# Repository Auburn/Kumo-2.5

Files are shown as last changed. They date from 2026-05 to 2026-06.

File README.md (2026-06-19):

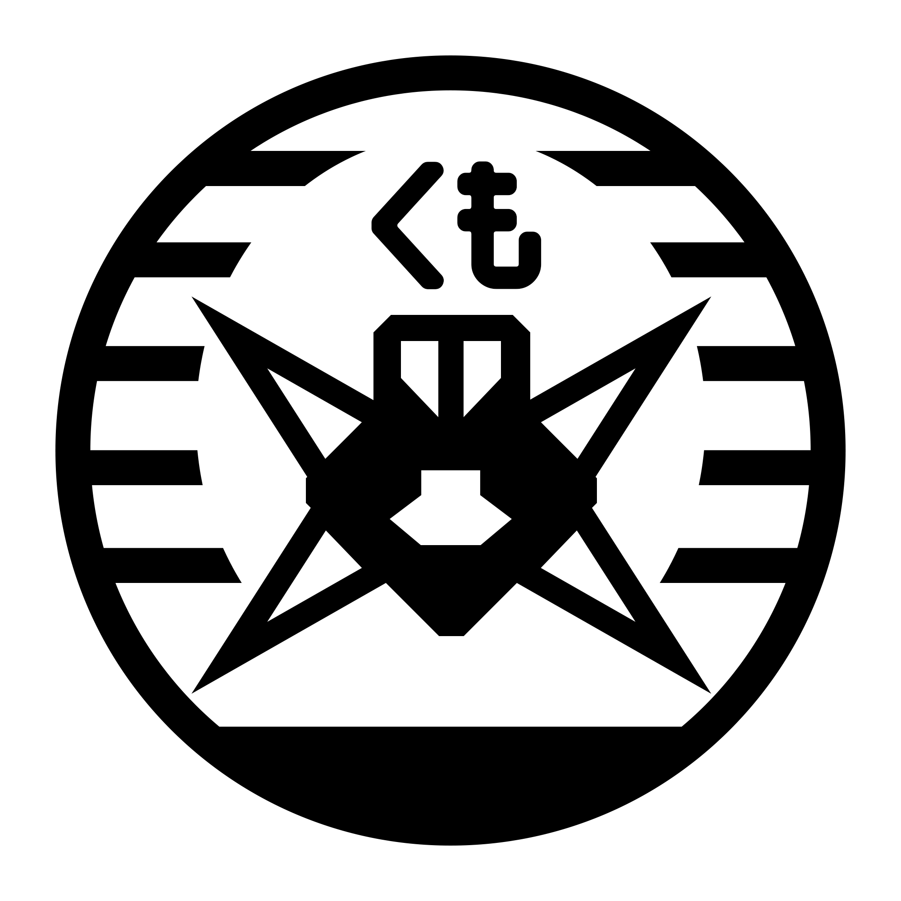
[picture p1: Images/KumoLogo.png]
Kumo Logo


# Kumo 2.5
A 2.5" drone frame. Star shaped dual arm design available both in printable and carbon fiber cut files in [[STL]] and [[CAD]] formats.

This project was born out of the desire for building a robust freestyle 2.5" 2S quad built from the ground up around the HDZero AIO15 and Lux camera. Something with a bit more power and wind resilience than a whoop, but still relatively quiet and survivable to crashes. Some of the mono-body frames seem to have lightweight arms that are a bit flimsy, thus the star shape was opted in the newer versions of the Kumo frame. 

My vision for this project was to create an open-source frame design that could be iterated and shared with accessible options. 

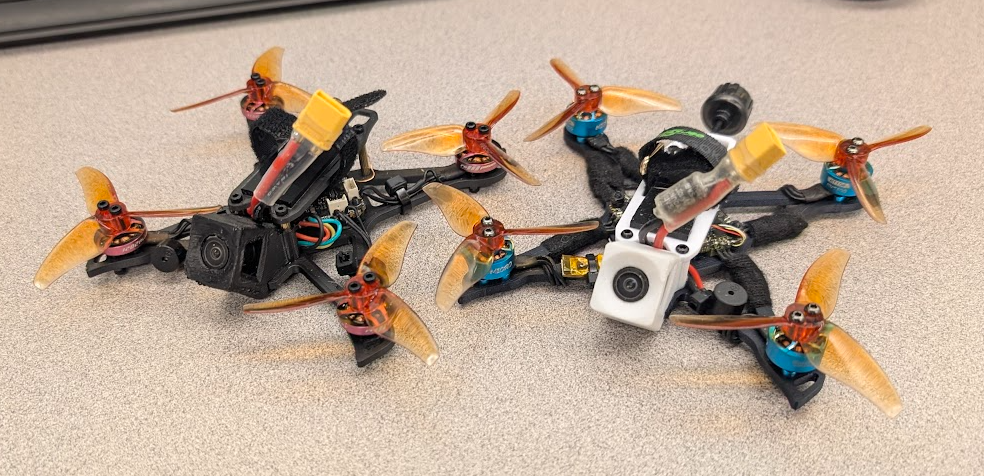
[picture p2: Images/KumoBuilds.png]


## Contents

1. [Elements](#elements)
2. [Design](#design)
3. [Recommended Setup](#recommended-setup)
4. [Tune](#Tune)
5. [Videos](#Videos)
6. [Authors](#Authors)
7. [Versions](#Versions)
8. [Changelog](#Changelog)

## Elements

- Open Source as CC-BY 4.0
- Designed as a more robust toothpick with AIO or other light stacks. Primarily the HDZero AIO15
- Squished X geometry (4mm stubbier to get the props a bit less in frame)
- Slam deck to keep center of gravity along propeller line
- Rigid Design
- Camera mount designed for 25/35deg HDZero Lux. Also compatible with the [Kayoumini camera mounts ](https://www.printables.com/model/1330393-kayoumini-camera-tpu-print-support)
## Design

### Frame Design
Cutout for HDZero AIO15 to reduce height while also keeping ports accessible.
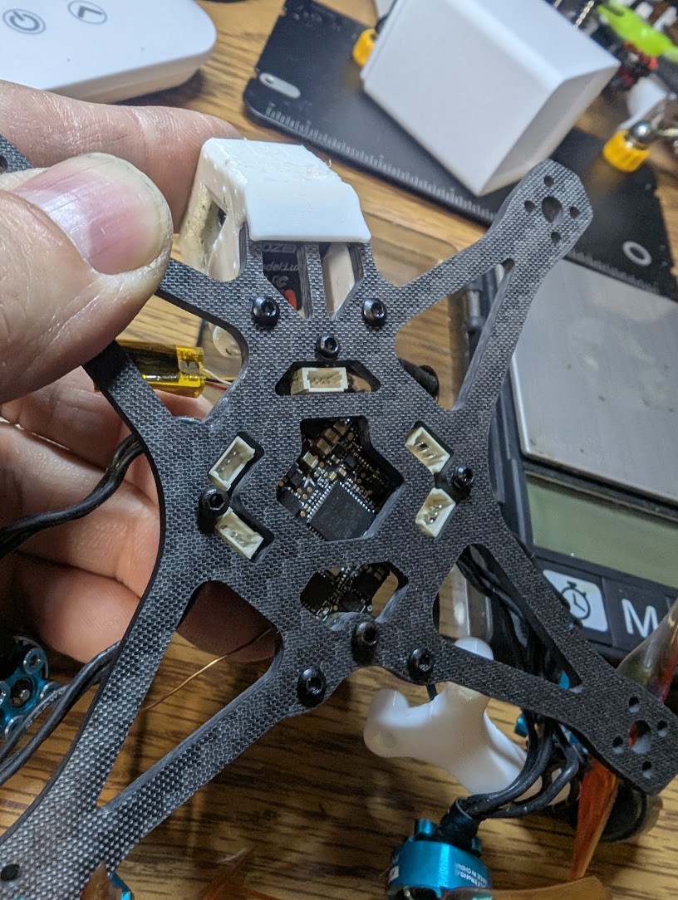
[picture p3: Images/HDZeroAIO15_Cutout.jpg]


Squished X geometry set at just under 85deg between front/back. Reduces prop in frame, however roll vs pitch movement requires less inertia due to weight distribution along Y axis.
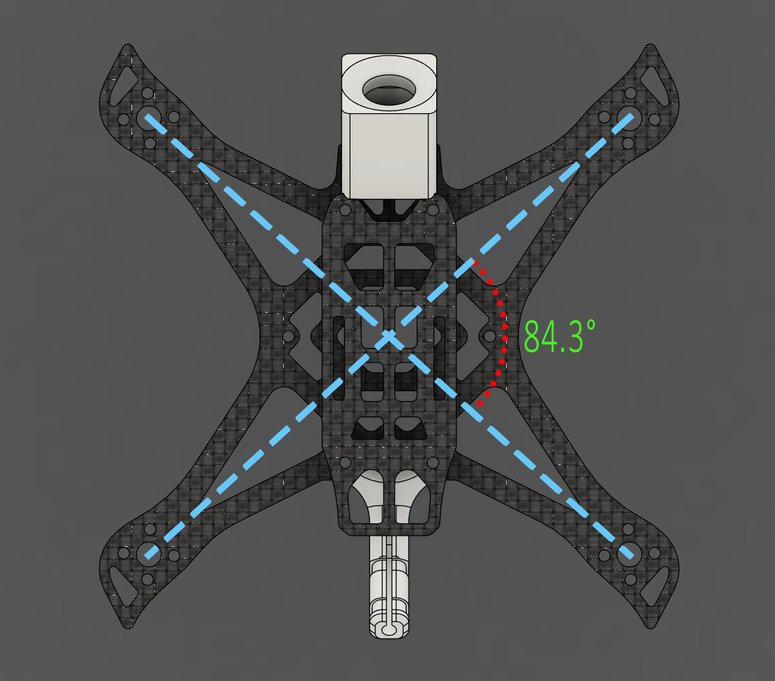
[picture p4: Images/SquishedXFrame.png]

#### Slam Deck and Center of gravity
Keeping the center of gravity low with 8-12mm standoffs helps reduce effort in flips. Sweet spot for avoiding battery strikes with props sits around 10-11mm standoff while also providing plenty of room for wire routing. For a tighter fit, 8-9mm standoffs can be used. Photo below is of 11mm standoff.
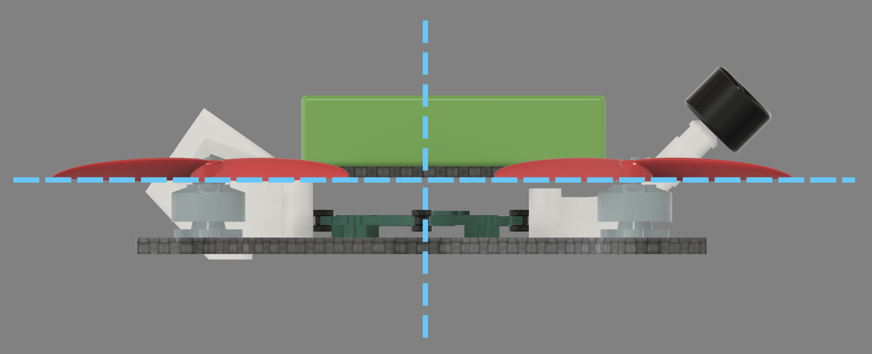
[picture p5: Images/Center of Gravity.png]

### Camera mount
Designed with compatibility in mind with camera mounts from [Kayoumini](https://www.printables.com/model/1330393-kayoumini-camera-tpu-print-support) This sample mount for HDZero Lux at 35 degrees offers a balance between racing and freestyle. Print in TPU to dampen vibrations and soften impacts.
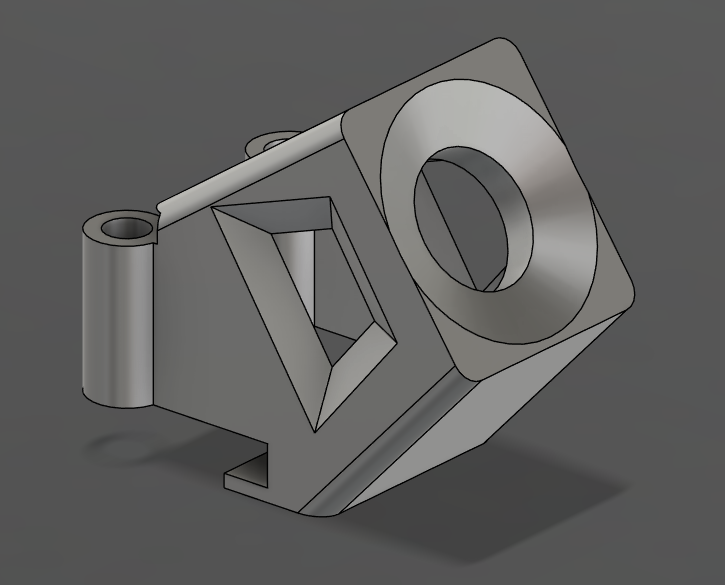
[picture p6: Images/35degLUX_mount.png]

### Printed frame vs Carbon Fiber
Original test builds used a variety of 3D printed versions yielding varying stiffness and weight. 
Thickened printed version in PETG-CF to increase stiffness and improve impact resilience. In this version I was still using the stick antenna from BetaFPV
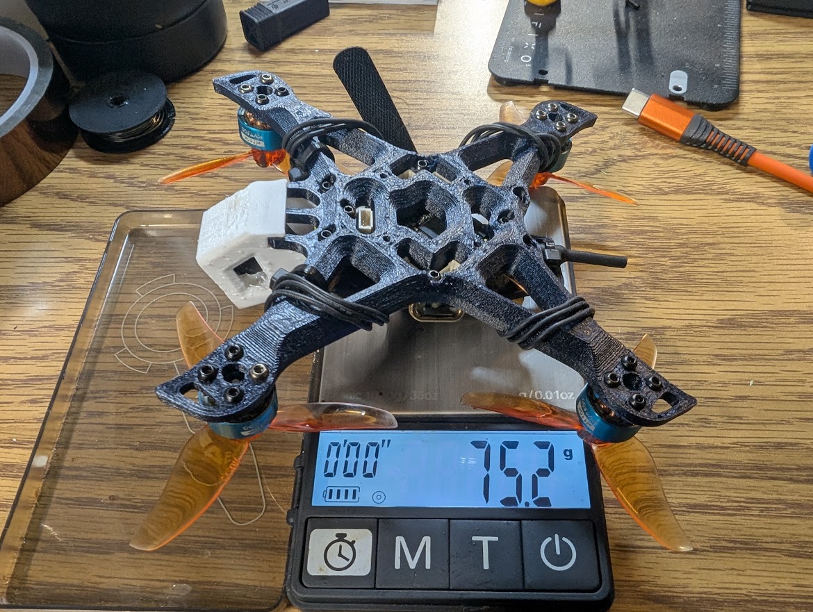
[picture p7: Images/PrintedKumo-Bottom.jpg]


Stubby version of frame cut from 2.5mm Carbon Fiber with RHCP antenna for improved weight and video signal
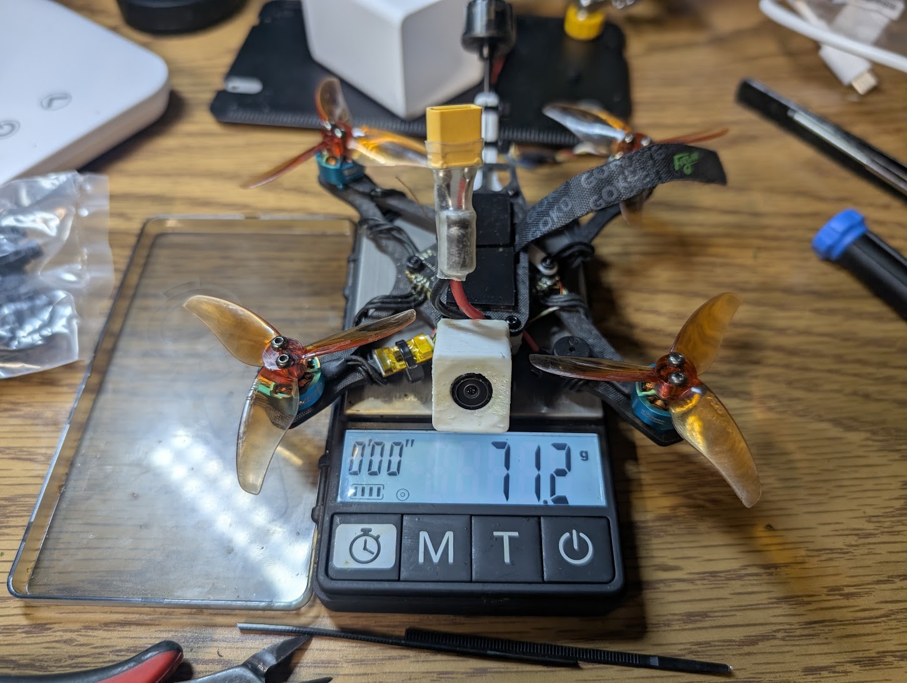
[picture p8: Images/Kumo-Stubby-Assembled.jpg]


Noise comparison between tunes of 3D printed (blue) and Carbon Fiber (red) variants of frame. The CF frame seemed to produce close to 10dB less noise thus requiring much less filtering  to improve responsiveness.
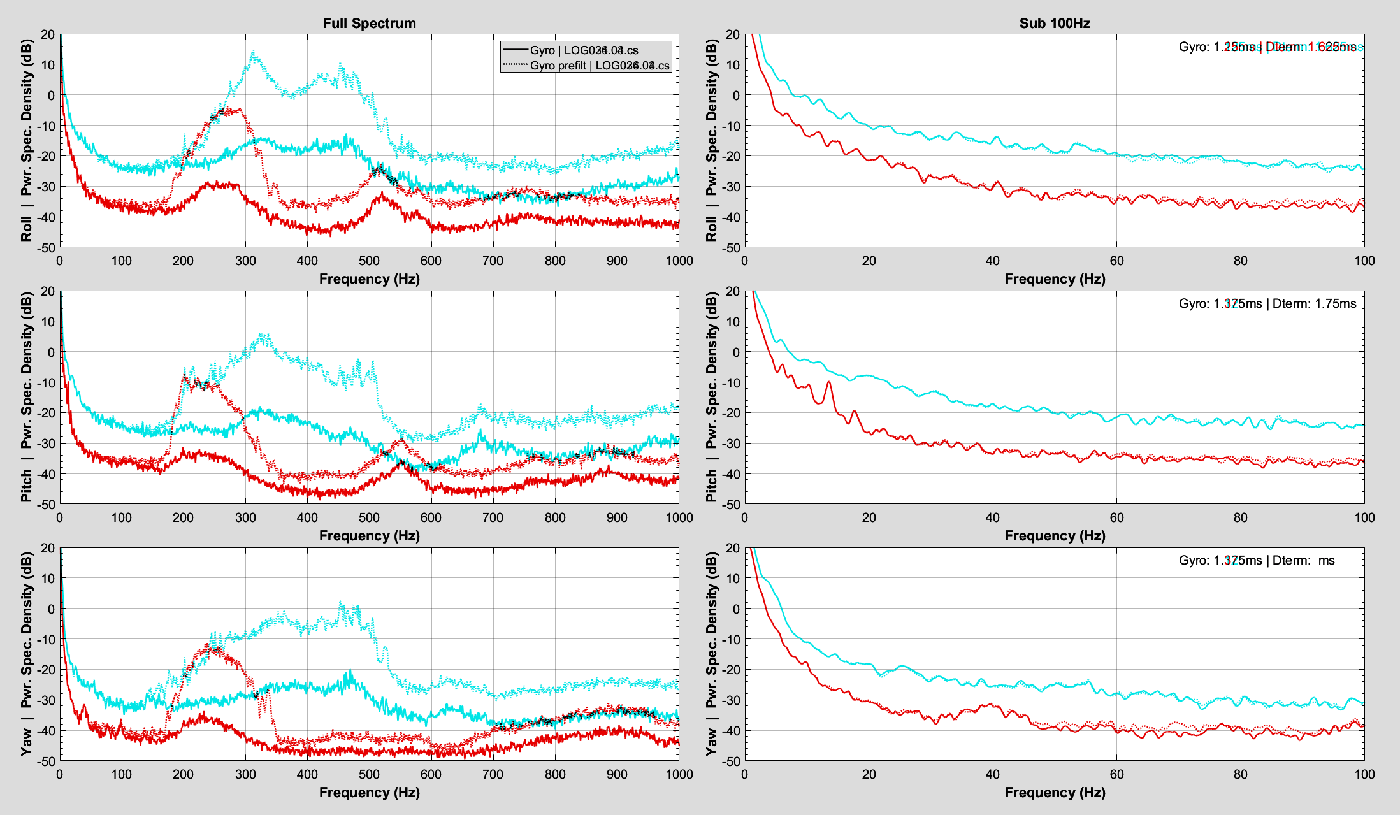
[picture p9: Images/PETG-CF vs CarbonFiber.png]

### Stubby vs Sharp
I created a light weight version of the frame for increased agility (and likely more fragile) stubby version weighing in at 10g for the base. Cut from 2.5mm thick CF 6K 2x2 Twill weave
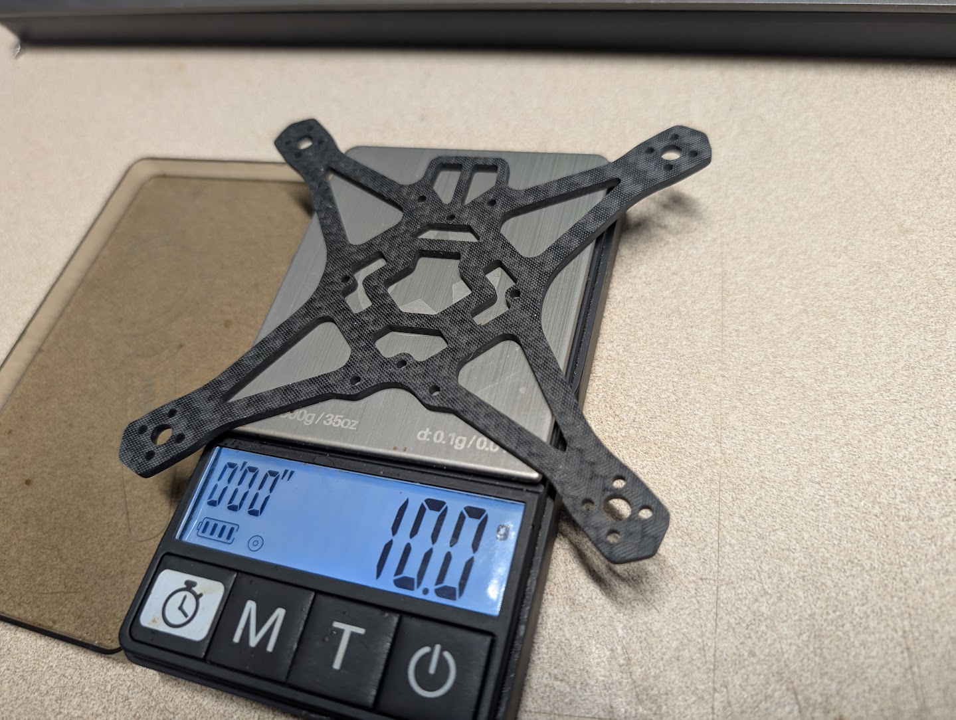
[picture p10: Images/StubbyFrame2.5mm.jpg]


And a heavier 3.4mm carbon (was listed as 3.1) cut from 6K 2x2 Twill weave. Added protrusion to add material in front of motor. Designed for more aggressive bashing, but adds 4.4g to previous design.
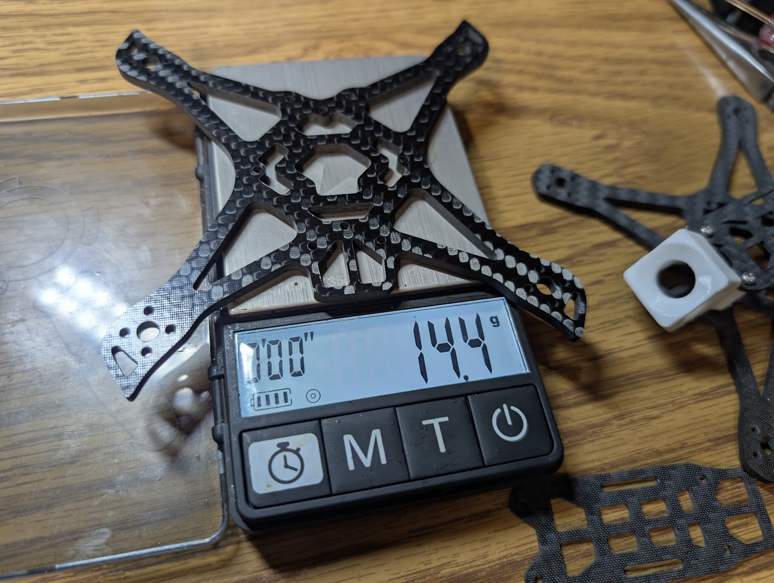
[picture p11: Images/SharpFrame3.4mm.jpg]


TPU plus CF stubby, top plate, standoffs and main screws comes in at 17.5g
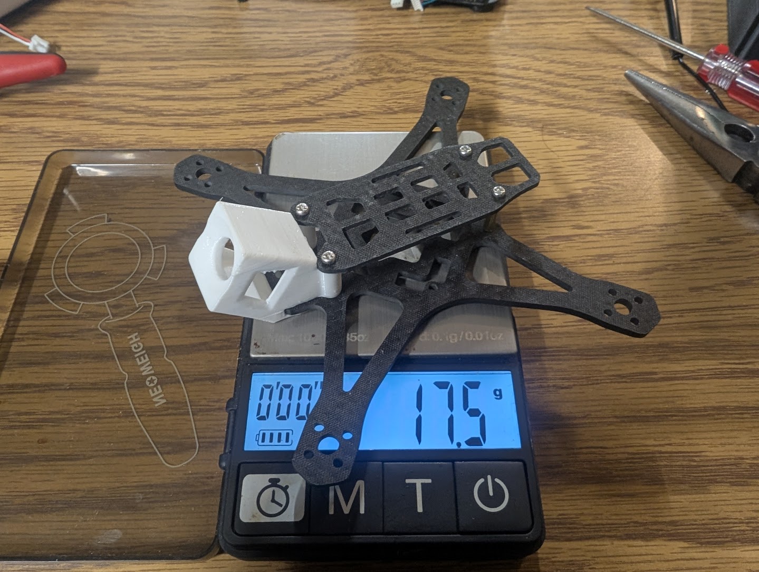
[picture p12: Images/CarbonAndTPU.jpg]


Top plate cut from 1.5mm CF 6k 2x2 twill. Designed with cut out towards the front for battery lead and extension on the back for battery deck/attachment for antenna.
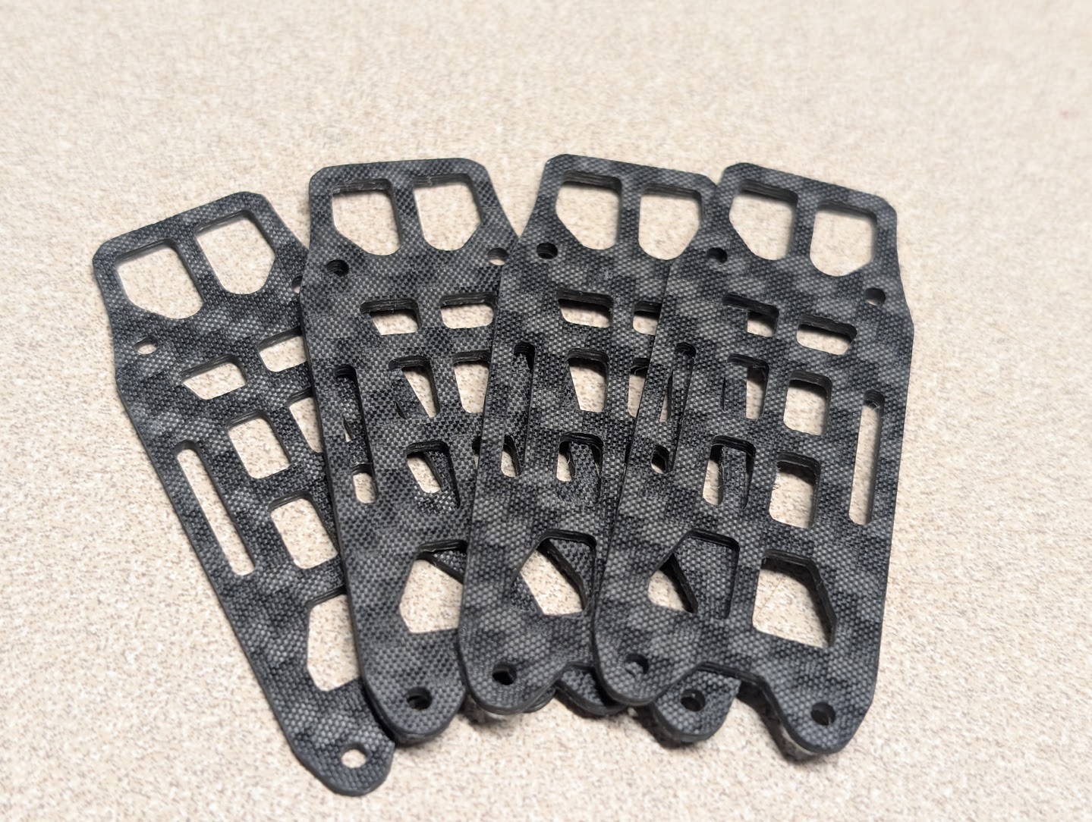
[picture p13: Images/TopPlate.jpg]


## Recommended-Setup

> [!NOTE]
> *At this size, every gram counts, so tradeoffs must be made to manage durability, range, battery/flight time and flight dynamics.* 

Key considerations for building: 
1. **Weight** of components: Antenna type, TPU mounts and motor guards, battery size. My goa was to have a dry weight under 70g and an AUW of under 100g. For this I found the stubby frame at 2.5mm thick with a circular polarized antenna provided a decent compromise in weight, range, signal quality. For a more racing style setup, I tested the Twiglet frame that allowed me to get as low as 50g using 12025 11000kv motors
2. **Power**: For motor and battery size considerations, I found the HDZero 15A felt solid with 2S in terms of maneuverability. 3S seemed to add quite a bit of weight which required much more throttle to power through sharp corners. With the 2S battery, finding a balance between 8000-11000kv would likely be ideal. I opted for heavier 1104 7500kv which added 4g, but gave me a bit more control with 2" pitch props over 12025 11000kv. That being said, the 12025 felt faster and twitchier, which may be preferable for pilots with better reaction time.
3. **Props**: I tested with GF 2520, 2540 and AVAN Rush (1.9" pitch). By performance, it felt like the Gemfan 2520 yielded the best performance and was less noisy than the AVAN rush. As nice as the AVAN rush felt, it had a high pitched scream that was somewhat unpleasant (and may be a nuisance around others). The GF2540 was explosive in power and worked well with the 1104 motors, but seemed better suited for racing and higher speed lines.
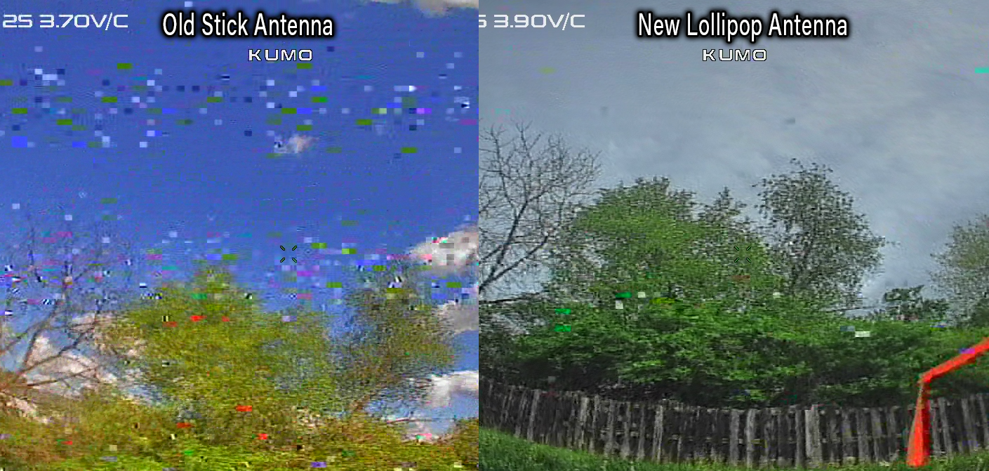
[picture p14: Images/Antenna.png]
4. **Antenna**: The default stick antenna that comes with the HDZero AIO15 caused a bunch of problems and no matter where I placed the antenna, I always seemed to struggle with noise and range issues. Opting for a circular polarized antenna that I could push further away from the body seemed to help quite a bit in transmission quality during punch-outs. I had tried other stick antennas such as a BetaFPV linear antenna for Air75, but performance still seemed quite bad. 
5. **Accessories**: The HDZero AIO15 does not come with a blackbox, which means if you wish to tune, you will need to attach an external recorder. I used a Flywoo OpenLager, which helped narrow down on some of the noise and responsiveness to cut down on propwash. I also added a simple buzzer as this tiny thing is super easy to lose. Adding 1g worth of wire/buzzer/ziptie is totally worth it in my book.
### Example build:
- HDZero AIO15 + Lux camera
- T-motor 1104 7500kv
- Gemfan Hurricane 2520
- Newbeedrone RHCP Honey Dipper Antenna
- 2S battery (450-580mAh)
- Active Buzzer and Flywoo OpenLager blackbox
## Tune
Betaflight defaults were fairly decent for me, but minor tweaks have helped improve propwash. Carbon fiber frame also was less susceptible to vibrations and required less filters.

PID profile settings are almost stock. I used PIDToolbox and suggestions from [this video](https://www.youtube.com/watch?v=ehvQm8Rqrzk). Angle limit was set to 30 during auto-wobble script.
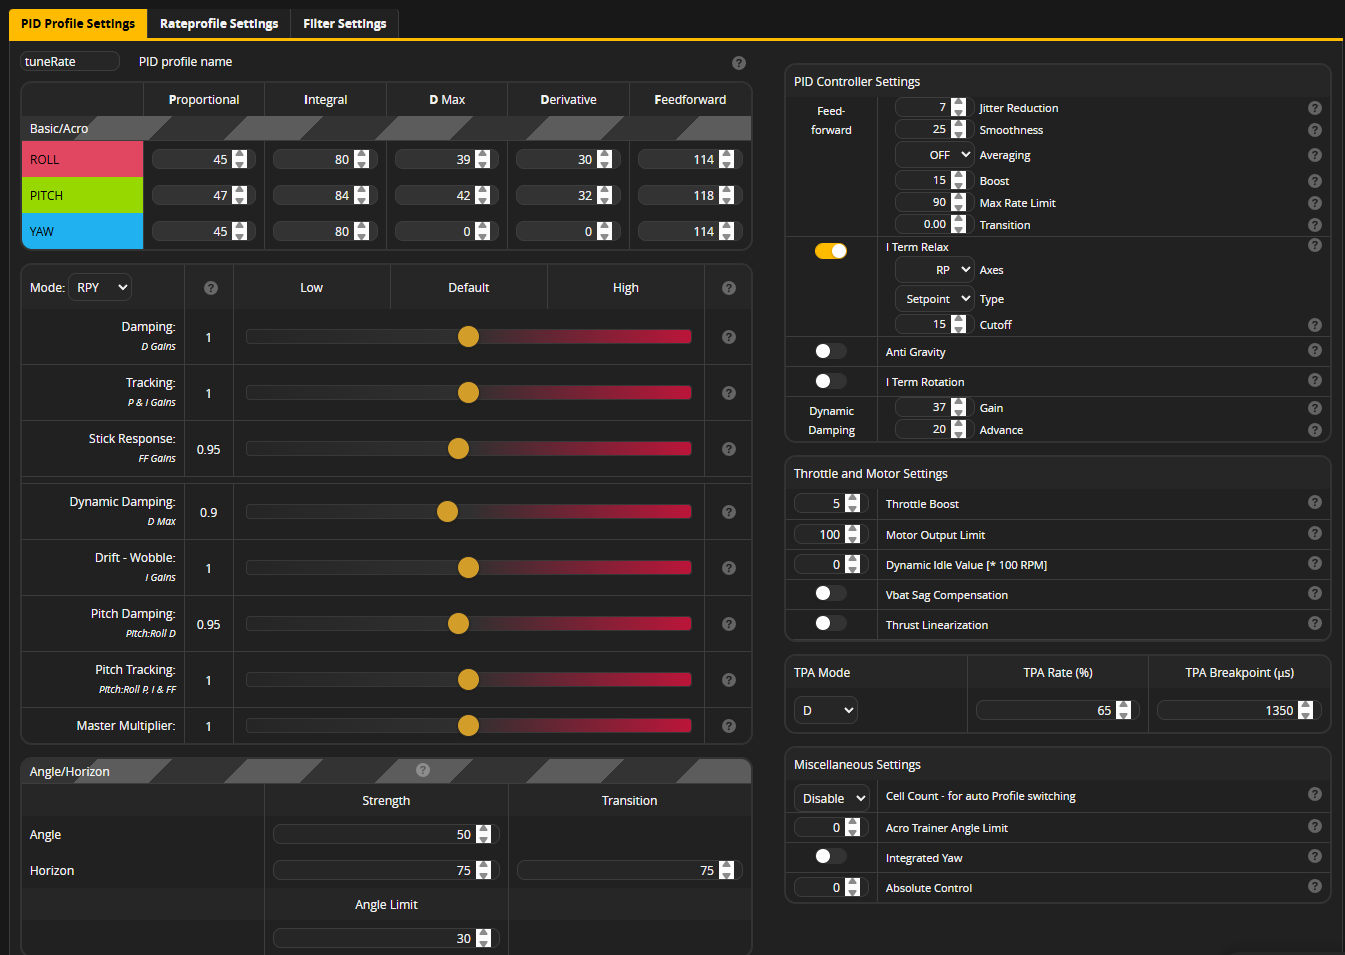
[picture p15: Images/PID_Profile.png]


For the filter, removing the first lowpass and tightening the notch filters helped reduce delay while still cleaning the noise.
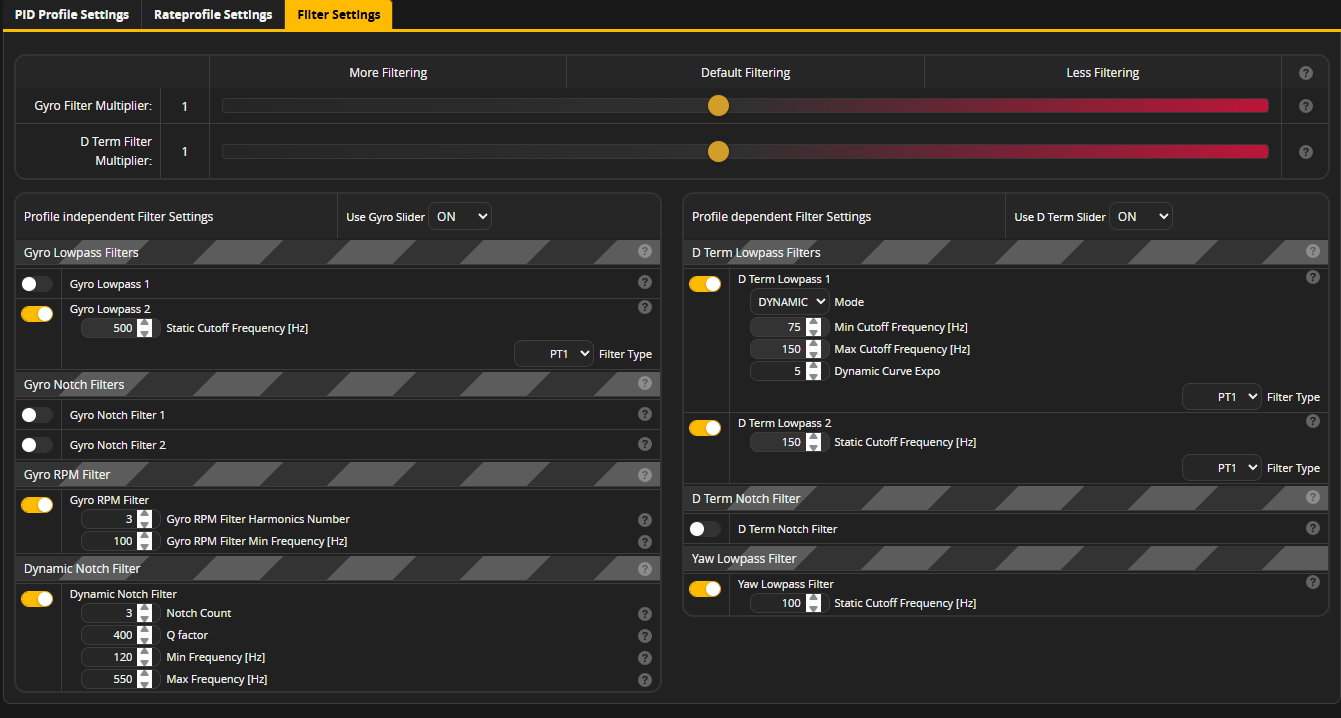
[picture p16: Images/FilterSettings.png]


I also set the filter weights and q value to the following:
`rpm_filter_weights = 100,60,70`
`rpm_filter_q = 1000`

Resulting first harmonics were still present, with **Roll** requiring a bit more attention, yet fairly solid from what I can tell.
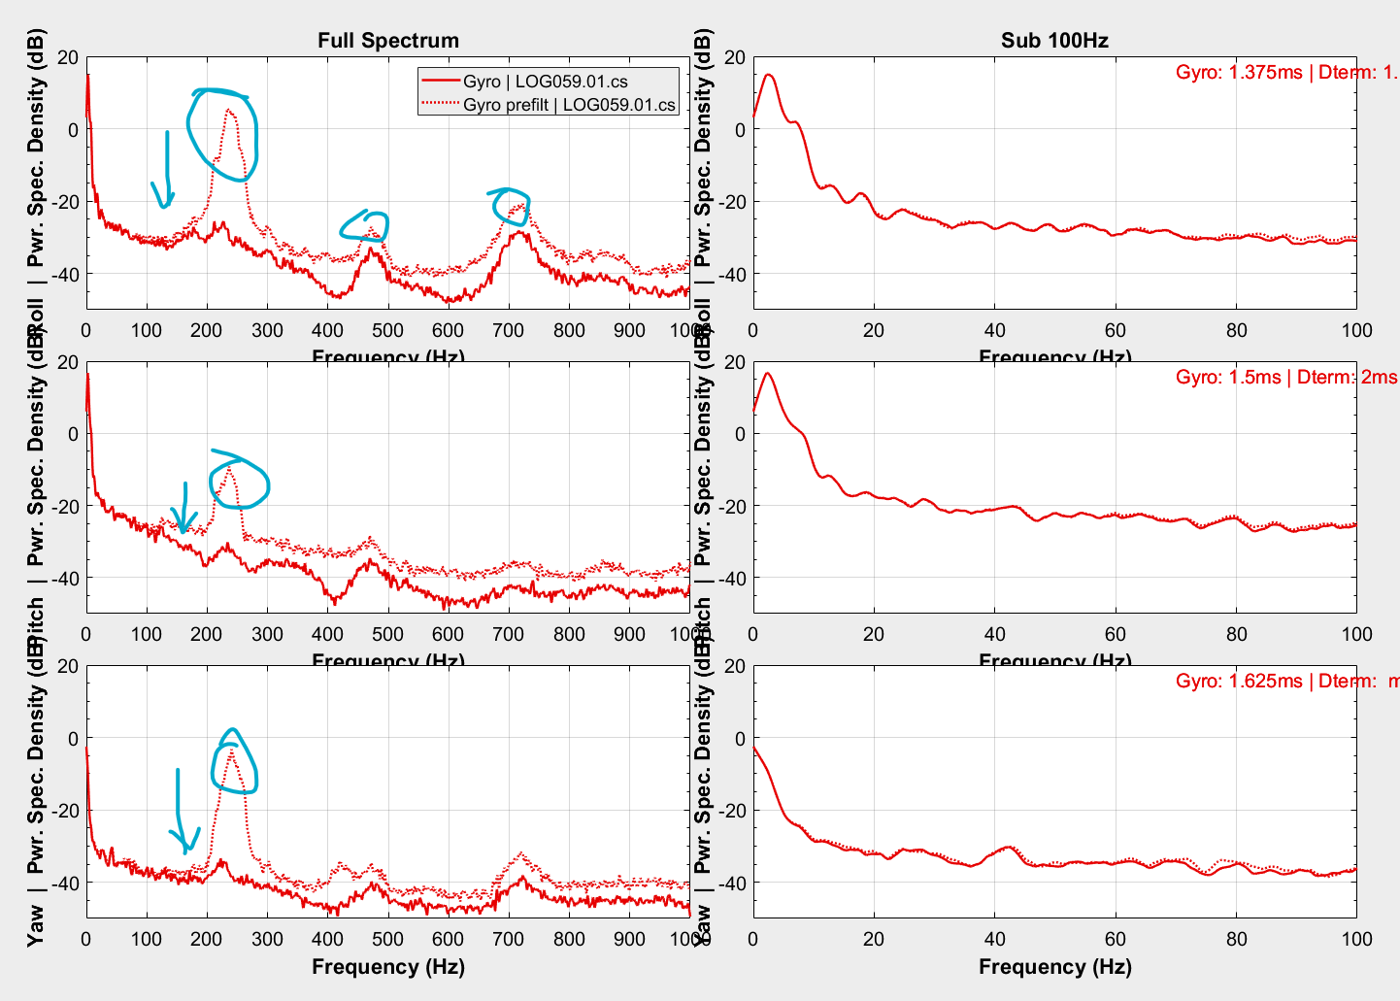
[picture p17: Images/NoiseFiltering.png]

## Videos

Kumo Frame analysis for stress concentration: (front impact)


Kumo Frame printed first flight

First Flight of 3D print|697 (http://www.youtube.com/watch?v=SoQ7cqYJ5XA)

Kumo Frame CNC cut on Millennium Mill

CNC Cut Stubby|697 (http://www.youtube.com/watch?v=ESLiF3WcUNc)
## Authors
The Kumo project was designed and contributed by:
- [Kumoi](https://github.com/kumoishibo): primary designer
- [Auburn](https://github.com/Auburn): Slim 3D print version & design contributions to main
## Versions
For a list of past created iterations, here is a [Google sheet of various versions with specs, components and photos](https://docs.google.com/spreadsheets/d/1-7FYr2rQ0BzAxG1OKXEforiyXhu9mfht/edit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)
List of file versions in repo:
- Kumo Main Version (Sharp version) 
- Kumo Slim (less material, more fragile)
- Kumo Stubby (similar to sharp version with stubby motor mount)
- Outdated versions (single arm design):
	- Kumo Frog (quite heavy and poorly designed skeletonized parts)
	- Kumo ChunkyFrog (more material, more cutouts, poor access to usb port)
	- Kumo Offaxis (interesting attempt to merge top/bottom plate with flipped parts. Too heavy, poor skeletonization, no top/bottom usb access, no battery strap)
## Changelog
- 6-19-2026: Additions of new slim 3D printable versions by [Auburn](https://github.com/Auburn) 
- 5-21-2026: Added Git Discussion, fixed M2 clearance on bottom AIO hole (Thank you Auburn!)
- 5-19-2026: Completed Documentation V1 and published to Reddit
- 5-5-2026: CNC cut stubby frame (youtube video above)
- 4-24-2026: [Tested with 3S... a bit scary](https://www.reddit.com/r/fpv/comments/1suqytk/probably_wasnt_meant_for_3s/)
- 4-20-2026: First flight of Star shaped Kumo frame (youtube video above)
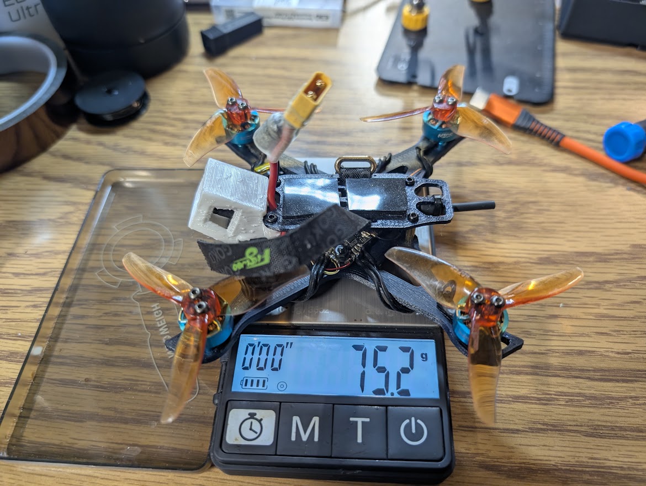
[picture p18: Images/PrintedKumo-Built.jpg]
- 4-19-2026: 3D printed version of frame built
- 4-16-2026: Experimental version of 3D printed frame. Felt very flimsy, added some material around standoff mounts.
- 4-6-2026: Camera mount complete
- 3-28-2026: Experimenting with [Flipped Z design](/CAD/OutdatedDesigns/Frog_MainBody.step)
- 3-27-2026: Stress tests for impact yields concerns with single arm design
- 3-25-2026: First version of Kumo frame  designed (looks like a squished frog)

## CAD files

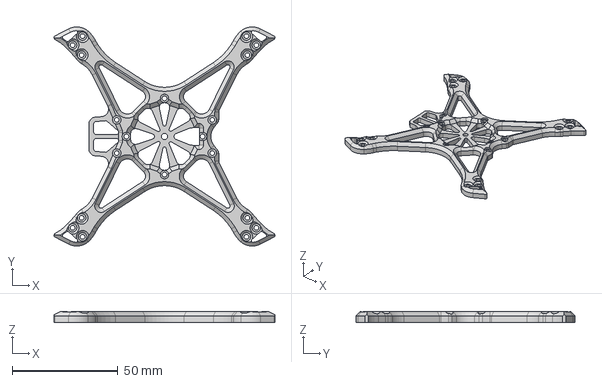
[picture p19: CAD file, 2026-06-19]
CAD/AlternateVersions/Kumo-MainBody-3DPrintSlim.step
104.6 x 103.8 x 5.00 mm

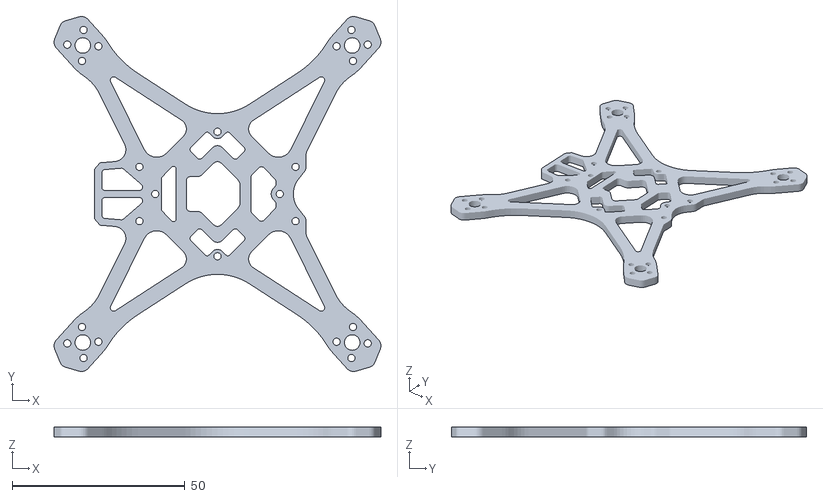
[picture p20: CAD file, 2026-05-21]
STL/AlternateVersions/Kumo-MainBody-Stubby-2.stl
94.6 x 102.8 x 3.00

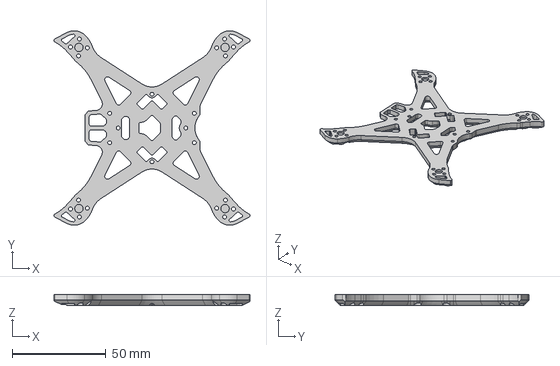
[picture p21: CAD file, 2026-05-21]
CAD/AlternateVersions/Kumo-MainBody_3DPrintableBasher.step
104.6 x 103.8 x 6.00 mm

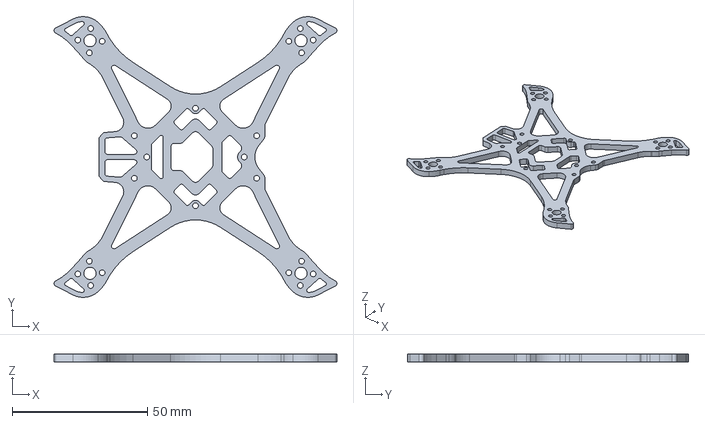
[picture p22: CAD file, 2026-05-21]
CAD/Kumo-MainBody.step
104.6 x 103.8 x 3.00 mm

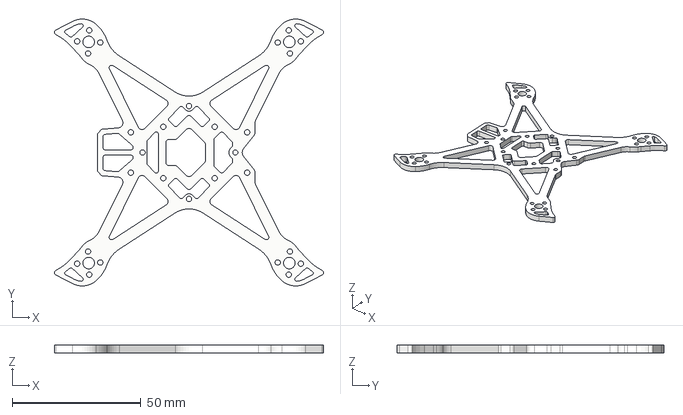
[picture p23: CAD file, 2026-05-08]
CAD/AlternateVersions/Kumo-MainBody-Slim.step
104.6 x 103.8 x 3.00 mm

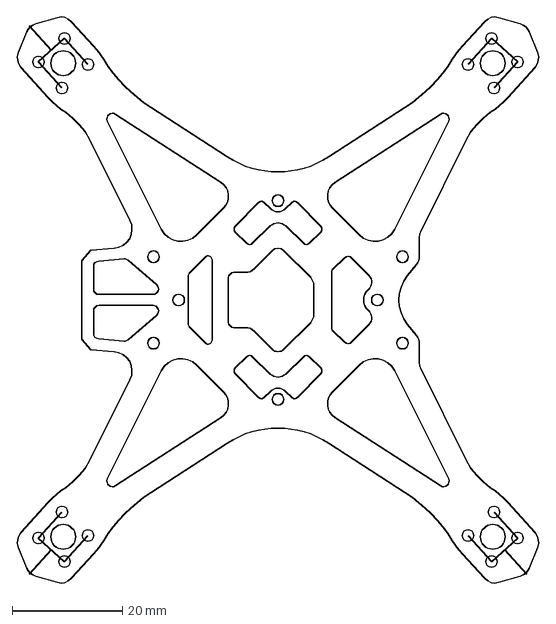
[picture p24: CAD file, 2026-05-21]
CAD/Stubby_Version.dxf
95.0 x 103.1 mm

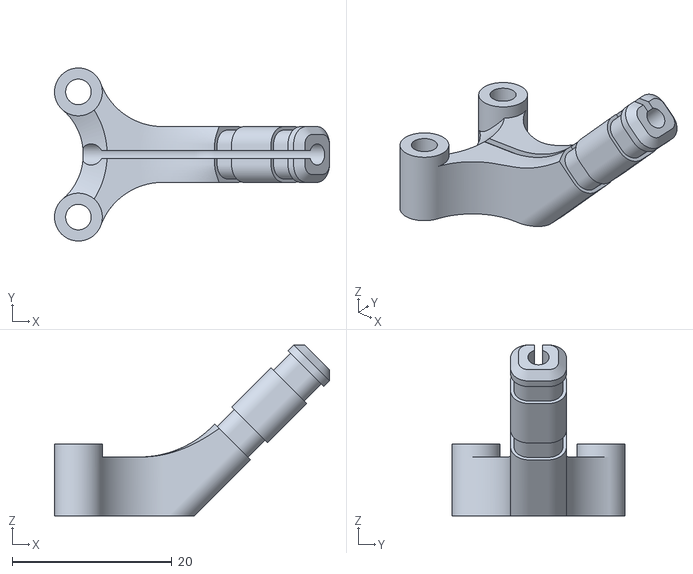
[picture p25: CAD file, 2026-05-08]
STL/AntennaMount-CP_D2.stl
34.5 x 21.7 x 21.4

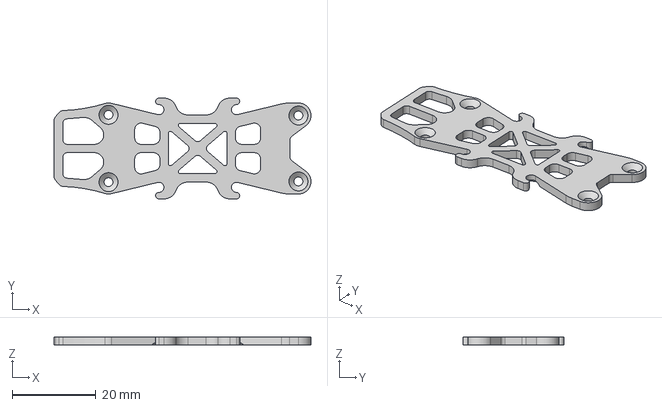
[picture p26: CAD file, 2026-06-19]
CAD/AlternateVersions/Kumo-TopPlate-Hooks.step
61.2 x 24.0 x 2.00 mm

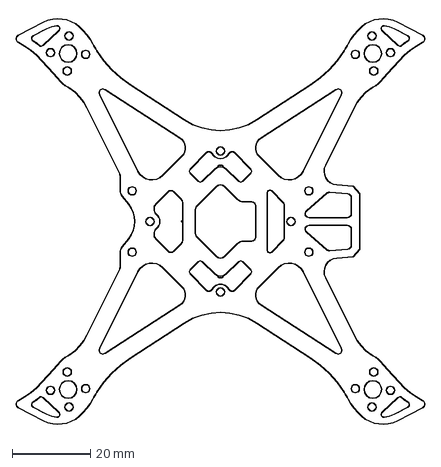
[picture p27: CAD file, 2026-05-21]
CAD/Standard_Version.dxf
104.6 x 105.0 mm

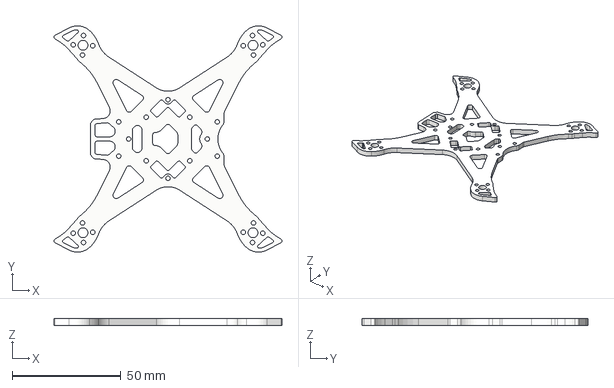
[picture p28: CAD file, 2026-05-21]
CAD/AlternateVersions/Kumo-ThickBase-Flat.step
104.6 x 103.8 x 3.00 mm

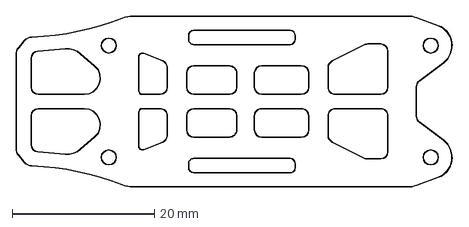
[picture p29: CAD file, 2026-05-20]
CAD/TopPlate.dxf
61.4 x 24.0 mm

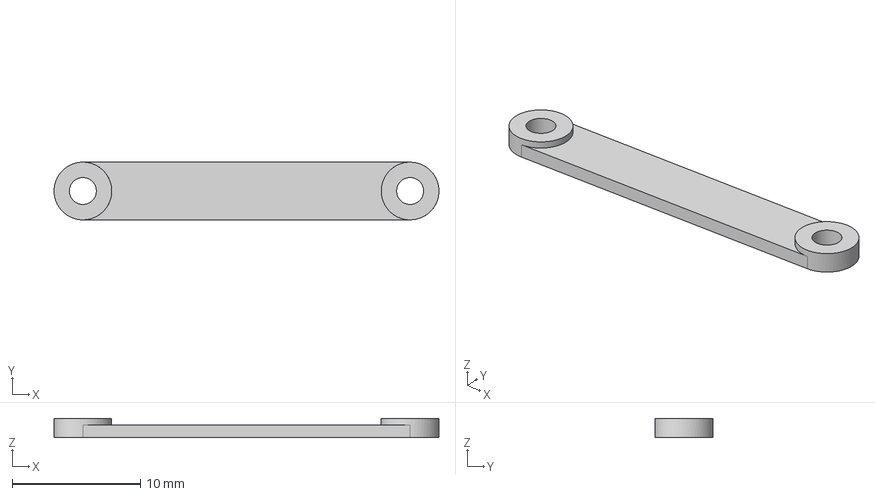
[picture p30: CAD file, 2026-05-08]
CAD/U.FL_Clamp.step
30.0 x 4.50 x 1.50 mm

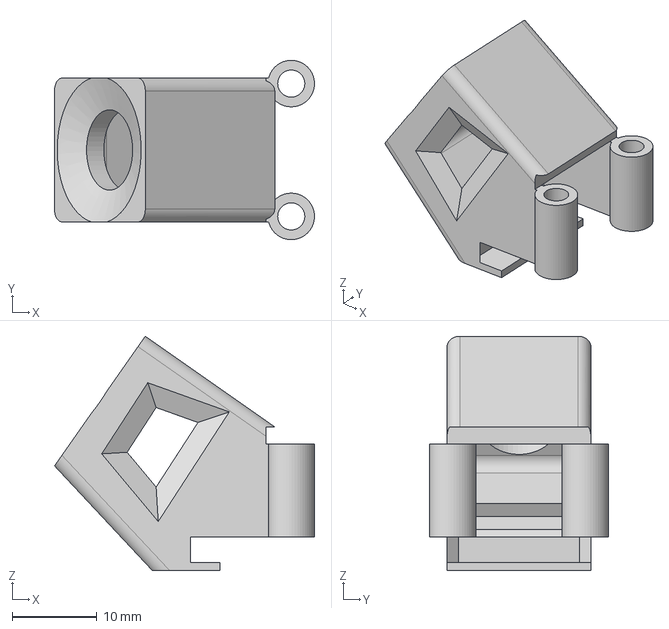
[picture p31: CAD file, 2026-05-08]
CAD/35degLUX_11mmStandoff.step
30.7 x 21.2 x 27.7 mm

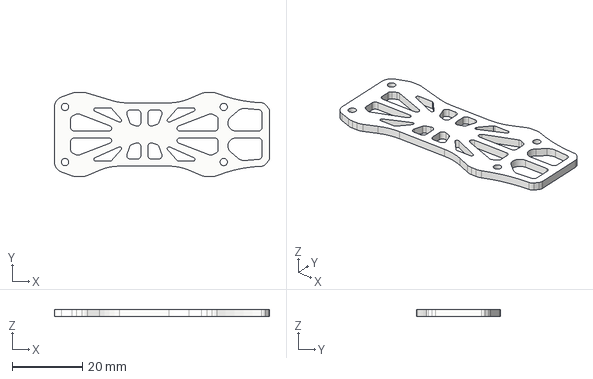
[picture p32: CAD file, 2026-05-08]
CAD/AlternateVersions/Kumo-TopPlate-Slim.step
61.2 x 24.0 x 2.00 mm

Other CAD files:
CAD/AlternateVersions/Kumo-MainBody-Stubby-2.5mm.step
CAD/AntennaMount-CP_D4.25mm.step
CAD/25degLUX_9mmStandoff.step
CAD/AlternateVersions/AntennaMount-CP_TopFront_D2.5mm.step
CAD/25degLUX_11mmStandoff.step
CAD/35degLUX_9mmStandoff.step
CAD/AlternateVersions/Kumo-MainBody-3DPrintSlim.f3d
CAD/AlternateVersions/Kumo-TopPlate-Hooks.f3d
CAD/AntennaMount-CP_D2.65mm.step
CAD/Kumo-TopPlate.step
CAD/OutdatedDesigns/ChunkyFrog_MainBody.step
CAD/OutdatedDesigns/Frog_MainBody.step
CAD/OutdatedDesigns/OffAxis_MainBody.step
STL/25degLUX_11mmStandoff.stl
STL/25degLUX_9mmStandoff.stl
STL/35degLUX_11mmStandoff.stl
STL/35degLUX_9mmStandoff.stl
STL/AlternateVersions/Kumo-MainBody-3DPrintSlim.stl
STL/AlternateVersions/Kumo-MainBody-Slim.stl
STL/AlternateVersions/Kumo-MainBody_3DPrintableBasher.stl
STL/AlternateVersions/Kumo-ThickBase-Flat.stl
STL/AlternateVersions/Kumo-TopPlate-Hooks.stl
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

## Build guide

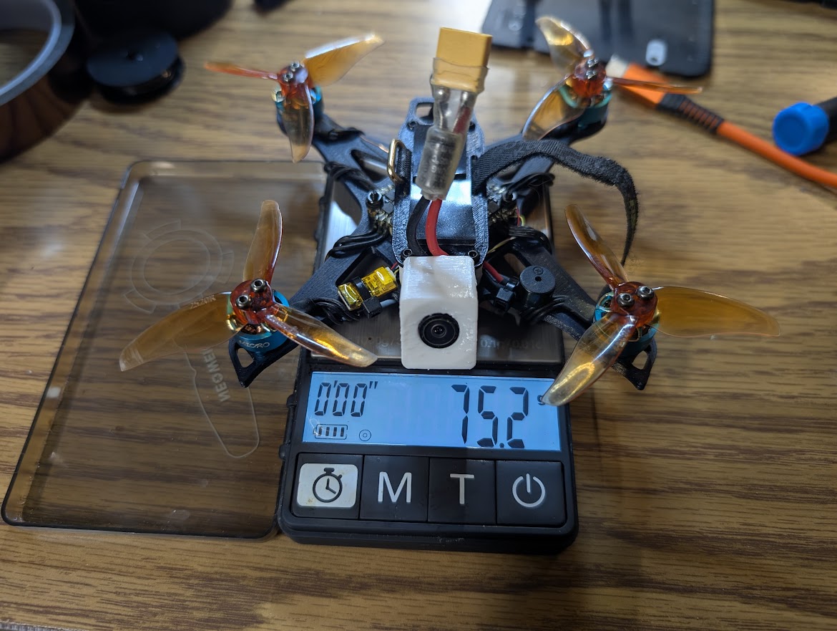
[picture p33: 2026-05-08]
Images/PrintedKumo-BuiltFront.jpg

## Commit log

2026-05-19 Filter results, author and tune info
    Filter results, author and tune info
2026-05-20 Added DXF files for Plates and F3D
    [Standard_Version.dxf, Stubby_Version.dxf, TopPlate.dxf]
2026-05-21 Fixed M2 clearance on botttom AIO hole
    Bottom AIO M2 hole was fixed to be 2.1mm instead of 2mm
    [Kumo-MainBody-Stubby-2.5mm.step, Kumo-MainBody-Stubby-2.stl, Kumo-MainBody.step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]
2026-06-15 3D print slim + top plate hooks CAD files
    [Kumo-MainBody-3DPrintSlim.f3d, Kumo-MainBody-3DPrintSlim.step, Kumo-TopPlate-Hooks.f3d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]
2026-06-15 3D print slim + top plate hooks STL files
    [Kumo-MainBody-3DPrintSlim.stl, Kumo-TopPlate-Hooks.stl]
2026-06-19 Moved to Alternate folder and updated Readme
    Reviewed and moved 3D print versions from Auburn to "AlternateVersions" directory and updated Readme with contributions
    [Kumo-MainBody-3DPrintSlim.f3d, Kumo-MainBody-3DPrintSlim.step, Kumo-MainBody-3DPrintSlim.stl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]
